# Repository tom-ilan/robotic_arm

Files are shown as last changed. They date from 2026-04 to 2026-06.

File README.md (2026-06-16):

# 🦾 3-Axis Robotic Arm Controller & Simulator

A high-performance, precision-controlled 3-axis robotic arm project featuring a mathematical Inverse Kinematics (IK) engine, a robust Arduino-based servo controller with EEPROM state persistence, and interactive command-line and graphical dashboards.

> 🎬 **Demo** — Watch smooth_glider.py in action

---

## 🌟 Key Features

* **Precision Inverse Kinematics**: Custom analytical geometric IK engine solving joint coordinates in real time for precise target tracking.
* **Sub-Degree Resolution Serial Protocol**: A binary serial packet protocol scaling float angles to centidegrees (1/100th of a degree) and packing them into compact 16-bit big-endian structures for optimal transmission speed and high accuracy.
* **Non-Volatile Memory (EEPROM)**: The Arduino firmware caches successful servo coordinates to the EEPROM on every valid command, preventing joint snapping/jerking when powered off and rebooted.
* **Startup Position Handshake**: On boot, the Arduino reads its last-known position from EEPROM (clamping uninitialized states to a safe $90^\circ$), moves there, and outputs an `INIT:base,bottom,top,gripper` handshake signal to coordinate seamless starting glides.
* **Multi-Mode Trajectory Planners**: Supports both immediate step-coordinate jumps (`rigid_glider.py`) and joint-space linear angle interpolation (`smooth_glider.py`) for smooth path planning.
* **3D Printable Mechanical Assets**: CAD models (STL/3MF/F3Z formats) located in the workspace under `version_1/` for physical arm manufacturing and prototyping.

---

# Assembly

## 🛠️ Hardware Requirements

1. **Microcontroller**: Arduino Uno, Nano, or similar AVR/ARM board.
2. **Servos**: 4x standard micro-servos (e.g., SG90 or MG90S).
   - **Servo 1**: Turntable Base (Pin 3)
   - **Servo 2**: Shoulder / Lower Arm (Pin 5)
   - **Servo 3**: Elbow / Upper Arm (Pin 6)
   - **Servo 4**: Gripper Claw (Pin 9)
3. **Power**: 5V external power supply (recommended for servos to prevent USB current limit trip).
4. **Screws**: 
    - 8x **M2 x 10mm**
    - 4x **M2.5 x 5mm**

## 🖨️ 3D Printing the parts

Located under **version_1** in the **final_print_parts** folder is the full final .stl files for printing, the settings used for a Bambu Labs P2S were the generic print settings with supports on. 

## 🪛 Assembly

1. After 3D printing the parts place the first servo into the base

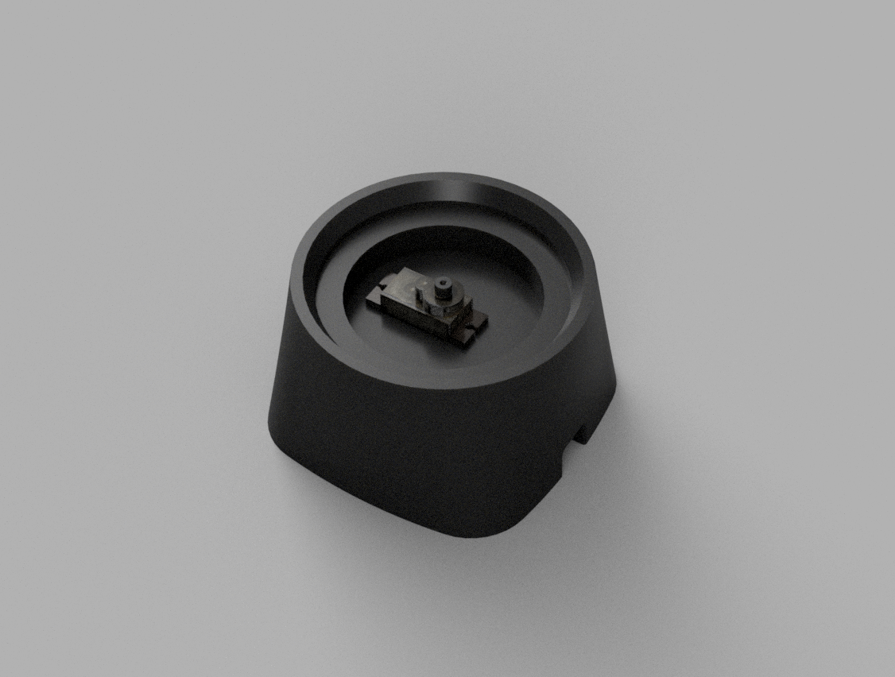
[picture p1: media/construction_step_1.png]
Step 1 - Servo seated in base housing


2. Then screw the top of the base onto the the servo

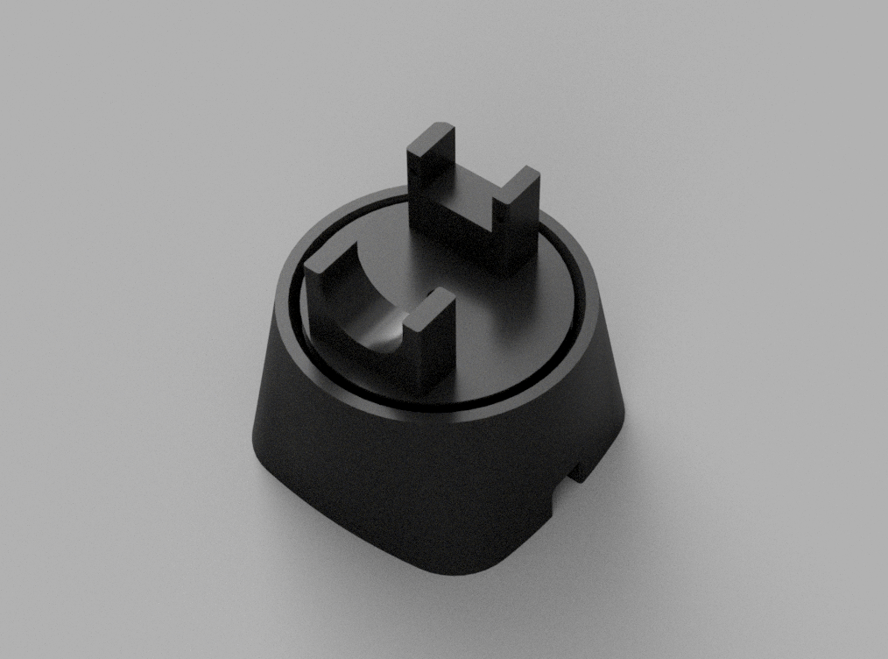
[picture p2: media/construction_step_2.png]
Step 2 - Base top placed onto servo


3. Now screw the lower arm and servo together

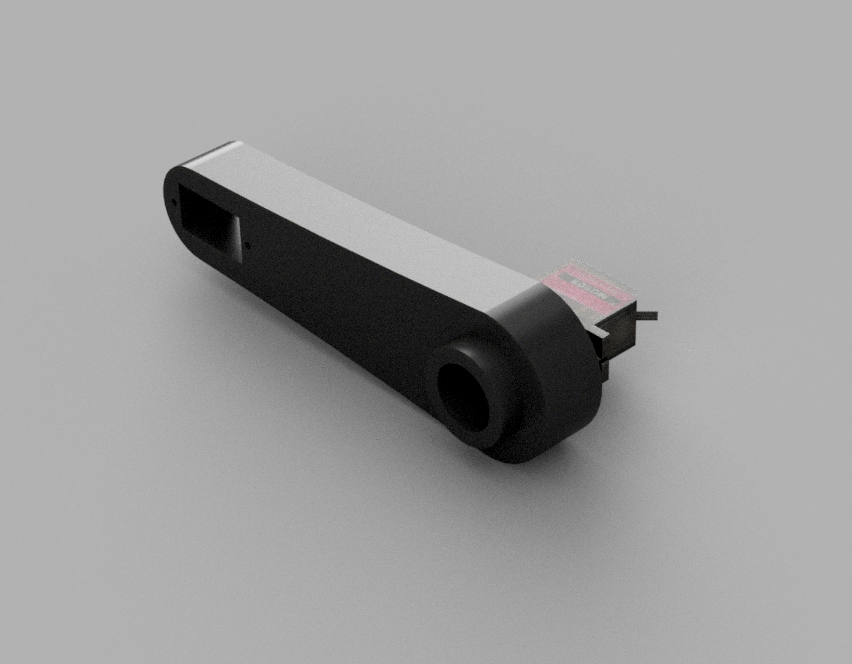
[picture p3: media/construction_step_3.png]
Step 3 - Lower arm assembled with servo


4. Slot the lower arm into the base 

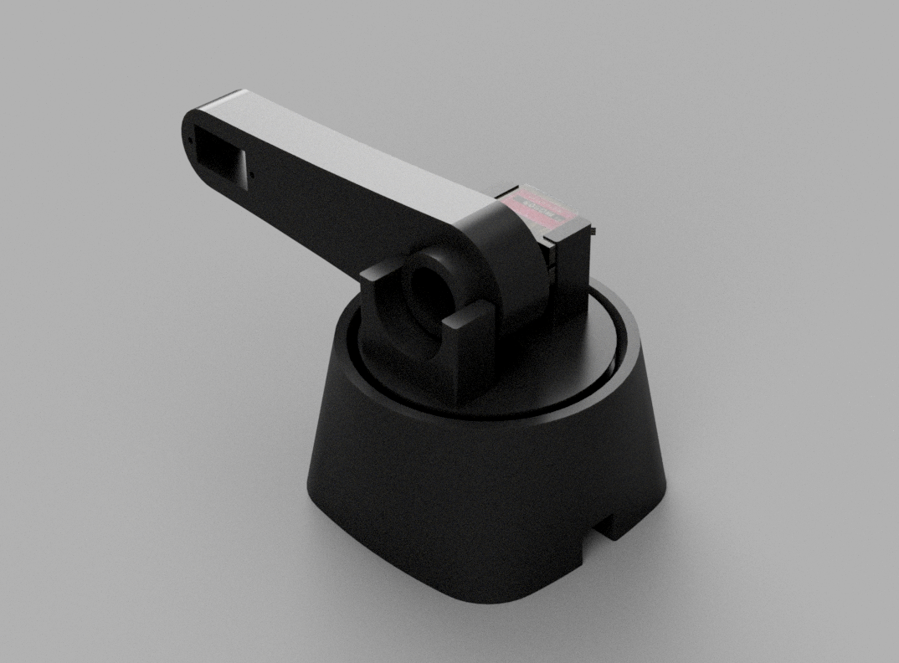
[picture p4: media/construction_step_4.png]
Step 4 - Lower arm slotted into base


5. Insert the servo to the end of the lower arm and upper arm and screw the upper arm to the lower arm 

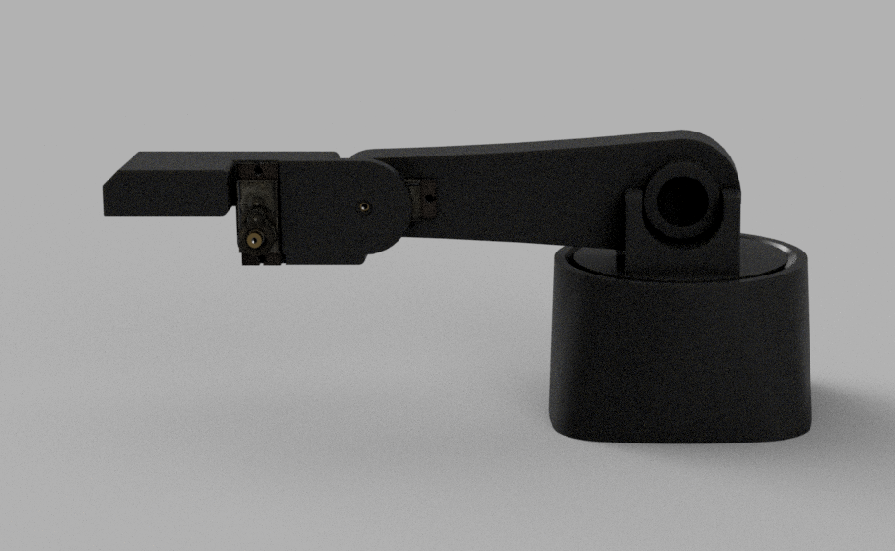
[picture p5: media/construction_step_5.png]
Step 5 - Upper arm connected at elbow joint


6. Screw the gripper onto the end of the upper arm

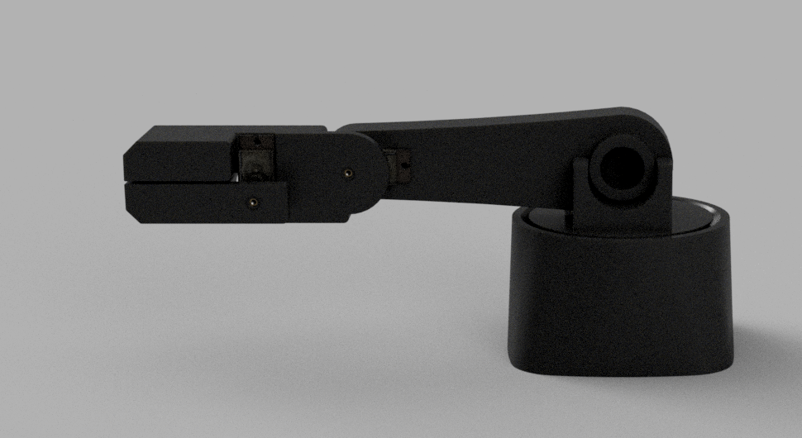
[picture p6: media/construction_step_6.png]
Step 6 - Gripper attached, full assembly complete

---

## 🚀 Getting The Arm Moving

### 1. Arduino Setup
1. Open [robot_arm_controller.ino](robot_arm_controller/robot_arm_firmware/robot_arm_controller.ino) in the **Arduino IDE**.
2. Connect your Arduino board via USB.
3. Select your Board and Port from the Tools menu.
4. Click **Upload** to flash the firmware.

### 2. Python Environment Setup
Install the necessary Python dependencies for the UI and serial driver:
```bash
pip install pygame pyserial pandas
```

### 3. Running the Controllers

#### 🎮 Interactive CLI (TUI) Modes:
* **Cartesian Control (X, Y, Z, Gripper)**:
  Allows typing target millimeter coordinates directly into the console.
  ```bash
  python robot_arm_controller/point_tui.py
  ```
* **Raw Angle Control (Base, Bottom, Top, Gripper)**:
  Allows writing raw joint-space angles.
  ```bash
  python robot_arm_controller/angle_tui.py
  ```

#### 📈 Waypoint Macro Executions:

* **Smooth Glider (Interpolated)**:
  Prompts for your waypoint CSV path, handshakes startup coordinates from the Arduino, glides smoothly to the starting point, and interpolates through each subsequent waypoint segment.
  ```bash
  python robot_arm_controller/smooth_glider.py
  ```
* **Rigid Glider (Immediate Steps)**:
  Prompts for a CSV path and executes sequential coordinates by sleeping for the designated duration between movements.
  ```bash
  python robot_arm_controller/rigid_glider.py
  ```

* **CSV formating**:

  **x cordinate** (mm), **y cordinate** (mm), **z cordinate** (mm), **gripper angle** (degree), **time** (seconds)
---

## 📐 Serial Communication Protocol

To ensure sub-degree accuracy without transmission overhead, the system uses a custom binary protocol using big-endian. Angles are scaled to **centidegrees** (multiplied by 100), converted to signed 16-bit integers, and sent as an 8-byte packet:

| Byte Index | Data Packed | Description |
|---|---|---|
| **0** | `Base High Byte` | Most Significant Byte of Base Angle |
| **1** | `Base Low Byte` | Least Significant Byte of Base Angle |
| **2** | `Shoulder High Byte` | Most Significant Byte of Shoulder/Bottom Angle |
| **3** | `Shoulder Low Byte` | Least Significant Byte of Shoulder/Bottom Angle |
| **4** | `Elbow High Byte` | Most Significant Byte of Elbow/Top Angle |
| **5** | `Elbow Low Byte` | Least Significant Byte of Elbow/Top Angle |
| **6** | `Gripper High Byte` | Most Significant Byte of Gripper Angle |
| **7** | `Gripper Low Byte` | Least Significant Byte of Gripper Angle |

---

## ⚙️ Mathematical Specification

The inverse kinematics algorithm maps $3\text{D}$ space $(X, Y, Z)$ into cylindrical coordinates, using `atan2` for robust base rotation, and solves planar arm equations via the Law of Cosines:

$$d = \sqrt{x_{inline}^2 + z_{inline}^2}$$

$$\theta_2 = \arccos\left(\frac{L_1^2 + L_2^2 - d^2}{2 L_1 L_2}\right)$$

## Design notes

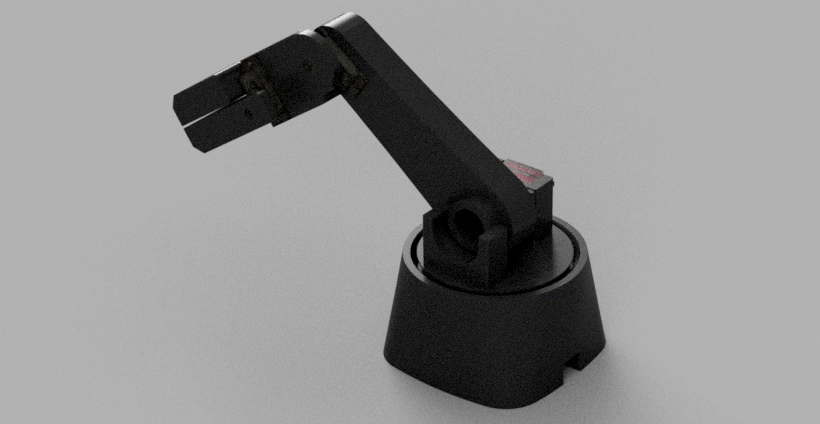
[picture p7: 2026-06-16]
media/social_image.png

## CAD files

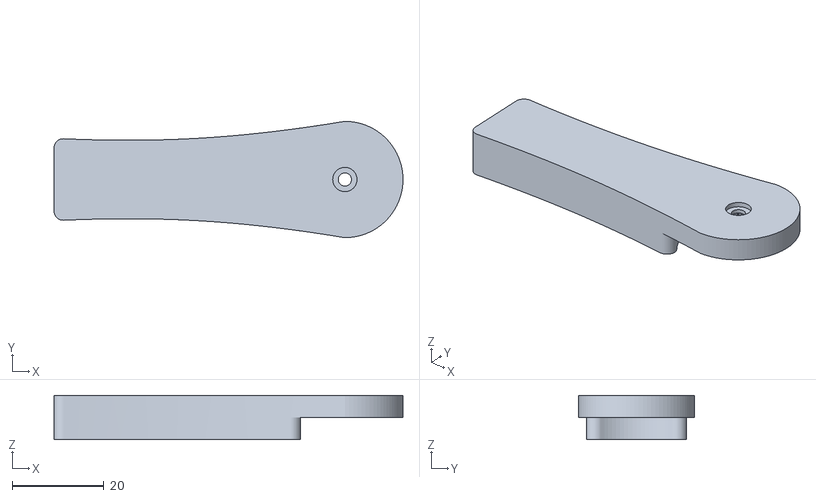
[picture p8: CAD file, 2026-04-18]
version_1/1.1/Upper_arm_2.stl
76.2 x 25.4 x 9.70

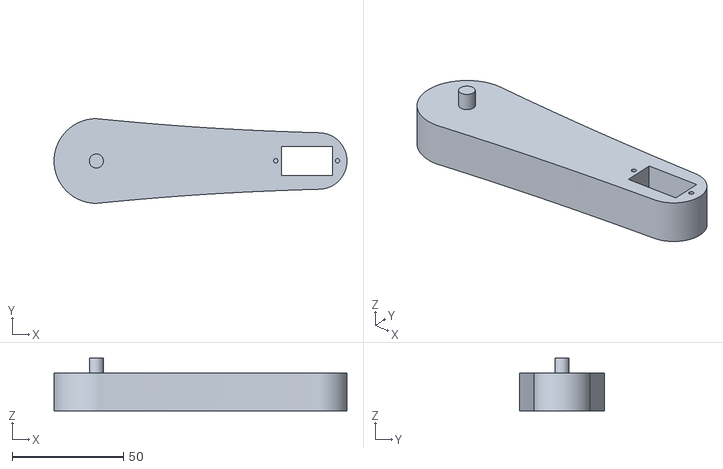
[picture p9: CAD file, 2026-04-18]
version_1/1.2/Lower_arm_2.stl
131.7 x 38.1 x 23.7

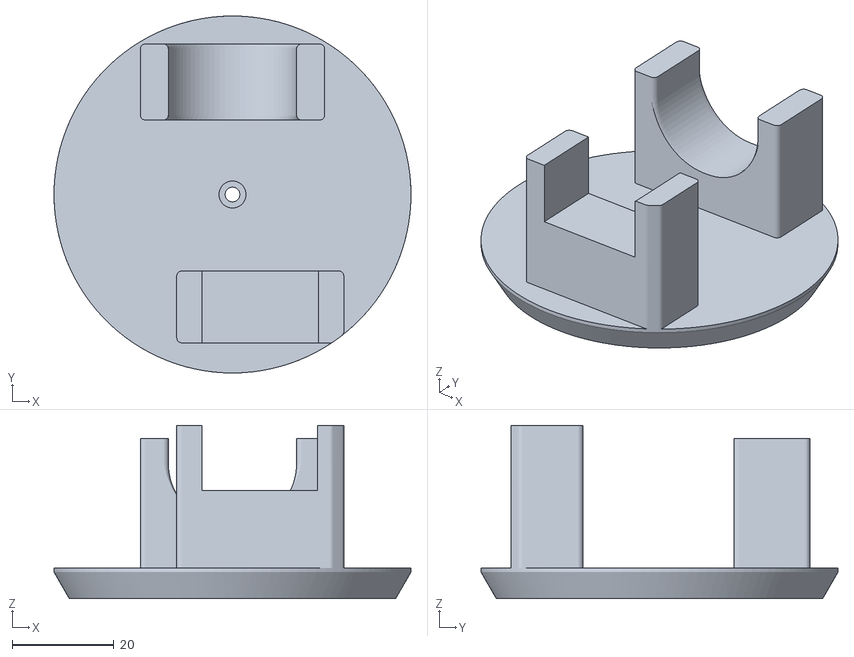
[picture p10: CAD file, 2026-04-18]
version_1/1.3/top_base_3.stl
70.0 x 70.0 x 34.0

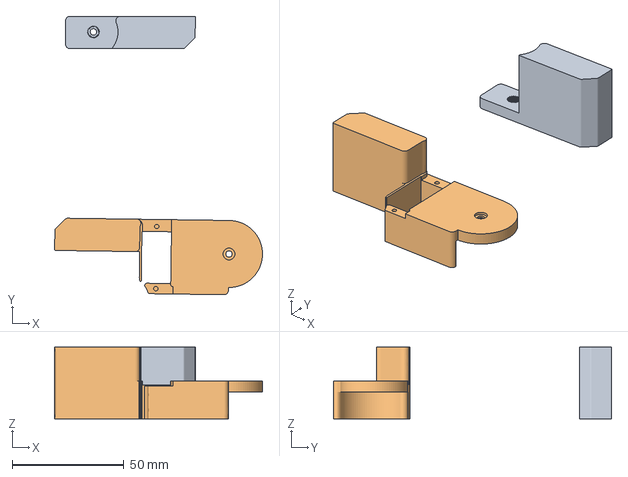
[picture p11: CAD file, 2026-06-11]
version_1/1.4/girpper.3mf
93.1 x 124.6 x 32.0 mm
girpper.stl
Top_arm_gripper_1.stl

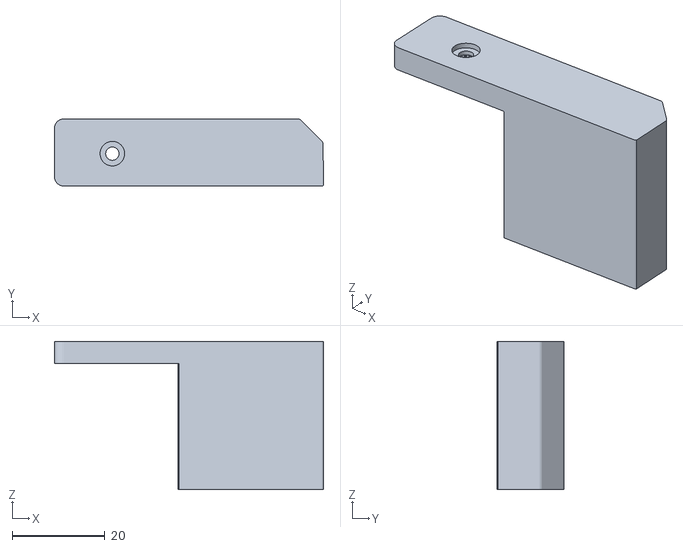
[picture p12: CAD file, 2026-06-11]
version_1/1.5/gripper_arm_2.stl
58.1 x 14.5 x 32.0

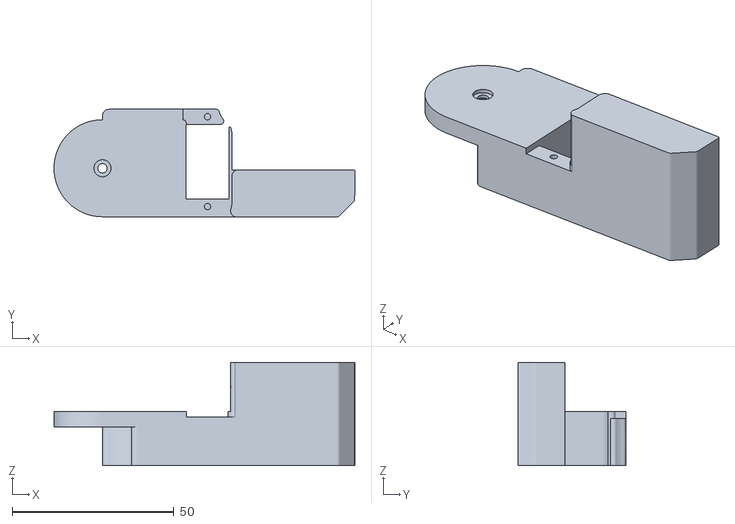
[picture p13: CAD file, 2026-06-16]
version_1/final_print_parts/uppper_arm_body_final_1.stl
93.1 x 33.2 x 32.0

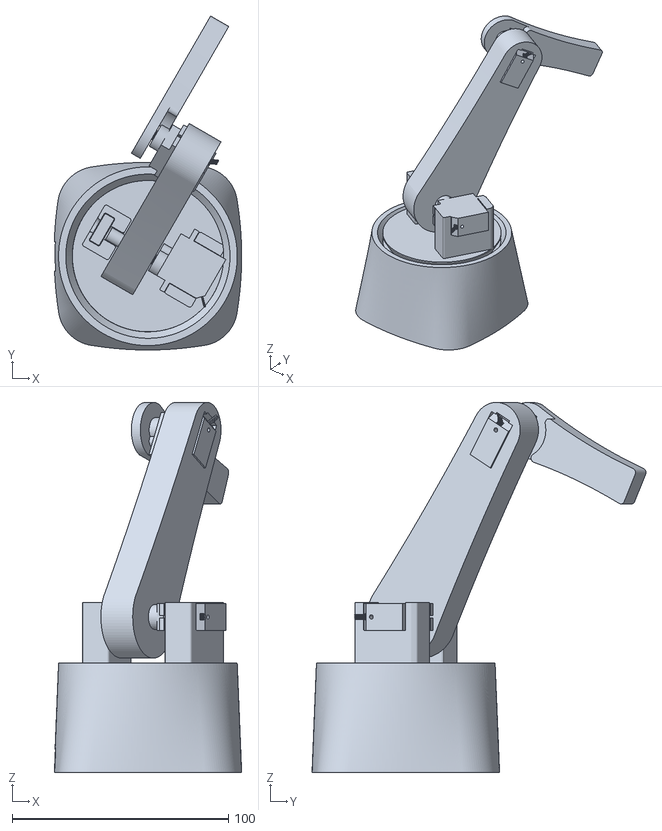
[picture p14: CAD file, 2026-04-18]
version_1/Robotic_arm_final_1.stl
86.7 x 154.6 x 171.3

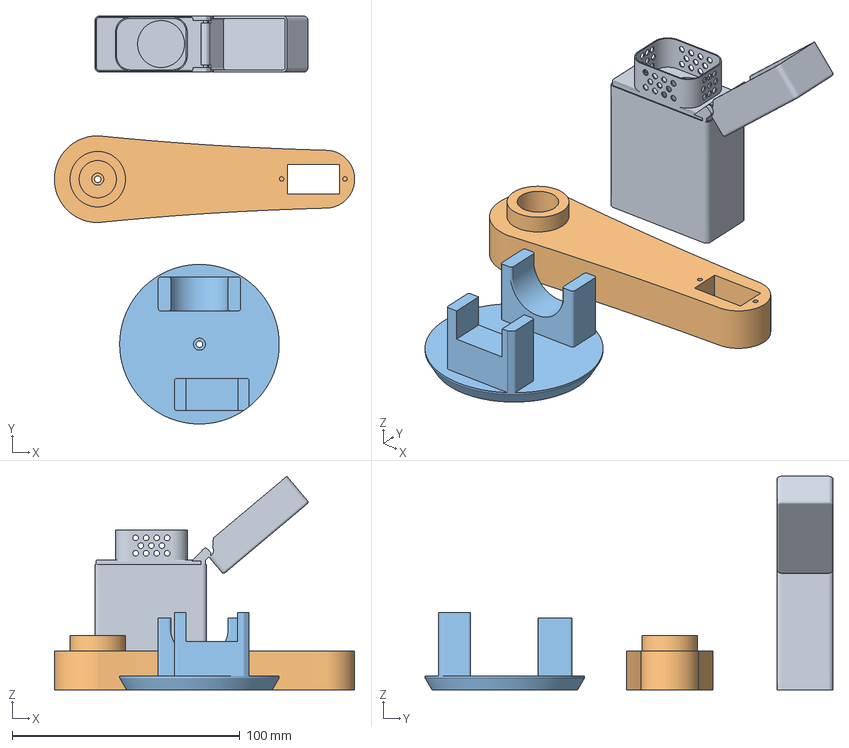
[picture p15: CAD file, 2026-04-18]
version_1/1.3/robotic_arm_print_2.3mf
131.7 x 179.0 x 93.7 mm
Lighter_Brayden.stl
Lower_arm_3.stl
top_base_3.stl

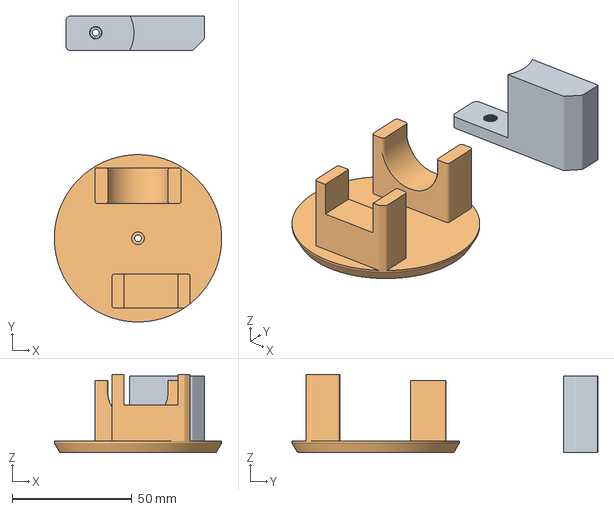
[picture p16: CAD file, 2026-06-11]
version_1/1.4/gripper_arm_2.3mf
70.0 x 128.0 x 32.8 mm
gripper_arm_2.stl
Base_top_4.stl

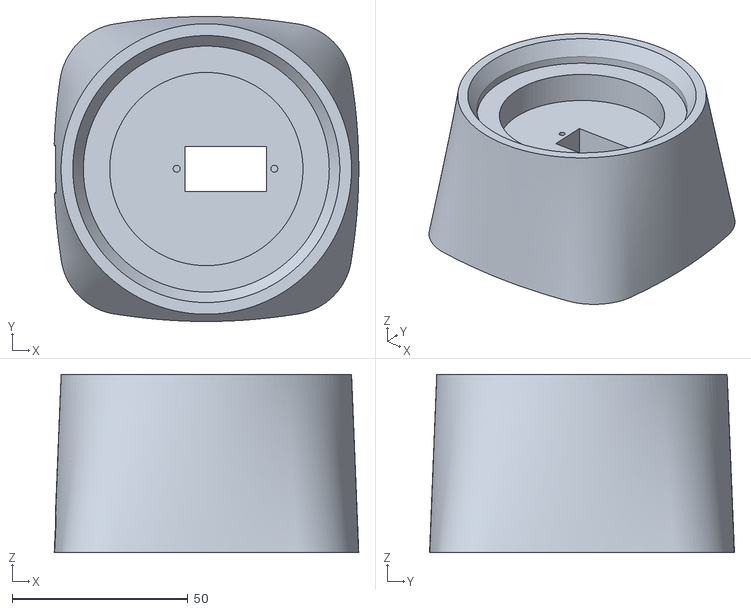
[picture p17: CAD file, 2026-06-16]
version_1/final_print_parts/base_bottom_final_1.stl
86.7 x 86.8 x 50.8

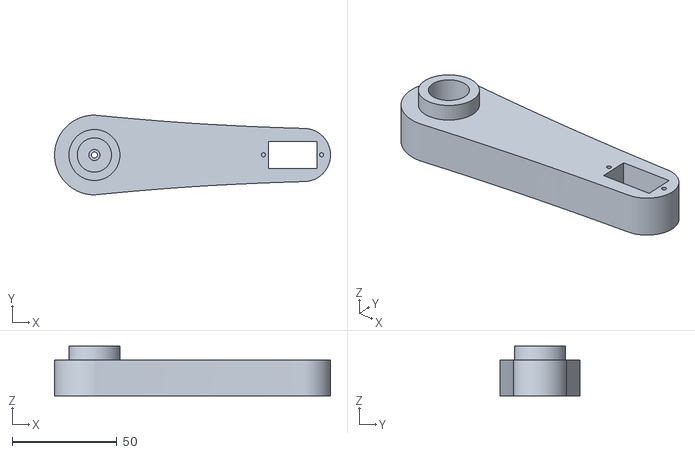
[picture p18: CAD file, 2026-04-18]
version_1/1.3/Lower_arm_3.stl
131.7 x 38.1 x 23.7

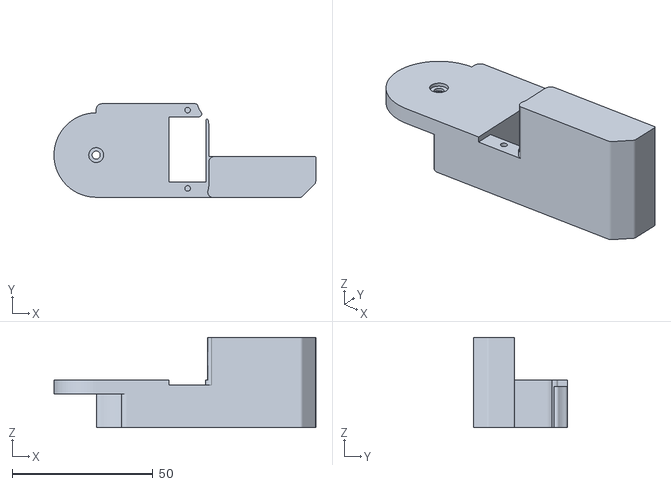
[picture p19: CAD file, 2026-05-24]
version_1/1.4/Top_arm_gripper_1.stl
93.1 x 33.2 x 32.0

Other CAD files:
version_1/1.1/Top_Base.stl
version_1/1.2/Base_top_2.stl
version_1/Top_Base.stl
version_1/1.1/Lower_arm.stl
version_1/Base_top_2.stl
version_1/final_print_parts/lower_arm_final_1.stl
version_1/1.1/Base.stl
version_1/1.1/Base_2.stl
version_1/1.1/Joint_Stopper_2.stl
version_1/1.1/Robotic_Arm_Print_1.3mf
version_1/1.4/girpper.stl
version_1/Lower_arm.stl
version_1/final_print_parts/base_final_top_1.stl

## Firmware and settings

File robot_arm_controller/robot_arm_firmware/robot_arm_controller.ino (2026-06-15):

#include <Servo.h>
#include <EEPROM.h>

// Servo set up
Servo servoOne;
Servo servoTwo;
Servo servoThree;
Servo servoFour;

void setup() {
  Serial.begin(9600);

  // Read positions from EEPROM
  int s1 = EEPROM.read(0);
  int s2 = EEPROM.read(1);
  int s3 = EEPROM.read(2);
  int s4 = EEPROM.read(3);

  // If EEPROM is uninitialized (255) or out of servo range, default to 90 degrees
  if (s1 < 0 || s1 > 180) s1 = 90;
  if (s2 < 0 || s2 > 180) s2 = 90;
  if (s3 < 0 || s3 > 180) s3 = 90;
  if (s4 < 0 || s4 > 180) s4 = 90;

  // Write initial positions to prevent the default 90-degree attach snap
  servoOne.write(s1);
  servoTwo.write(s2);
  servoThree.write(s3);
  servoFour.write(s4);

  // Print startup angles in a recognizable single-line format
  Serial.print("INIT:");
  Serial.print(s1);
  Serial.print(",");
  Serial.print(s2);
  Serial.print(",");
  Serial.print(s3);
  Serial.print(",");
  Serial.println(s4);

  // Servo attaching to pins with explicit pulse range
  servoOne.attach(3, 500, 2500); // base
  servoTwo.attach(5, 500, 2500); //bottom
  servoThree.attach(6, 500, 2500); //top
  servoFour.attach(9, 500, 2500); //gripper
}

void loop() {

  /* 
  1) Checks if there is incoming data in serial from python servo controller
  2) If there is assign each number (0-180) received to which servo it will control
  */

  if (Serial.available() >= 8) {

    byte servoOneBig = Serial.read();
    byte servoOneLittle = Serial.read();

    byte servoTwoBig = Serial.read();
    byte servoTwoLittle = Serial.read();

    byte servoThreeBig = Serial.read();
    byte servoThreeLittle = Serial.read();

    byte servoFourBig = Serial.read();
    byte servoFourLittle = Serial.read();

    // Print raw bytes separately (avoid second-argument overload)
    Serial.print("Raw bytes -> S1: ");
    Serial.print((int)servoOneBig);
    Serial.print(" ");
    Serial.print((int)servoOneLittle);
    Serial.print("  S2: ");
    Serial.print((int)servoTwoBig);
    Serial.print(" ");
    Serial.print((int)servoTwoLittle);
    Serial.print("  S3: ");
    Serial.println((int)servoThreeBig);
    Serial.print(" ");
    Serial.println((int)servoThreeLittle);
    Serial.print("  S4: ");
    Serial.println((int)servoFourBig);
    Serial.print(" ");
    Serial.println((int)servoFourLittle);

    int servoOneInput = twoByteCentiDegreeTooFloat(servoOneBig, servoOneLittle);
    int servoTwoInput = twoByteCentiDegreeTooFloat(servoTwoBig, servoTwoLittle);
    int servoThreeInput = twoByteCentiDegreeTooFloat(servoThreeBig, servoThreeLittle);
    int servoFourInput = twoByteCentiDegreeTooFloat(servoFourBig, servoFourLittle);

    // Prints what each servo got as input
    Serial.print("Decoded deg -> S1: ");
    Serial.print(servoOneInput);
    Serial.print("  S2: ");
    Serial.print(servoTwoInput);
    Serial.print("  S3: ");
    Serial.println(servoThreeInput);
    Serial.print("  S4: ");
    Serial.println(servoFourInput);

    //Writes the angles inputed to each servo
    floatServoDriver(servoOne, servoOneInput);
    floatServoDriver(servoTwo, servoTwoInput);
    floatServoDriver(servoThree, servoThreeInput);
    floatServoDriver(servoFour, servoFourInput);

    EEPROM.write(0, servoOneInput);
    EEPROM.write(1, servoTwoInput);
    EEPROM.write(2, servoThreeInput);
    EEPROM.write(3, servoFourInput);
  }
}

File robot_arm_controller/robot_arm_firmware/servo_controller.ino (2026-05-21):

#include <Servo.h>

// This function recives two bytes which make up one angle in centidegrees (byte1 and byte2) and returns the combined float
float twoByteCentiDegreeTooFloat(byte byte1, byte byte2){
  // promote to int before shifting so the high byte isn't lost
  int high = ((int)byte1) << 8;
  int centiDegreeByte = high | (int)byte2;
  float centiDegreeFloat = (float)centiDegreeByte;

  // Converts centidegrees to degrees
  float degreeFloat = centiDegreeFloat / 100.0;

  return degreeFloat;
}


void floatServoDriver(Servo &servo, float degree){
   // Map degrees (0-180) to microseconds (500-2500µs)
   int microseconds = map(degree, 0, 180, 500, 2500);
  
   servo.writeMicroseconds(microseconds);
   Serial.println(microseconds);
   delay(100);
}

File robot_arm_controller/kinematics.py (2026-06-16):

import math

# PHYSICAL CONFIGURATION
# Easily adjust the mechanical arm segment lengths here:
BOTTOM_ARM_LENGTH_MM = 100.0   # Shoulder-to-Elbow length (Shoulder)
TOP_ARM_LENGTH_MM    = 64.0    # Elbow-to-End-Effector length (Elbow)

TOP_MOUNTING_OFFSET_ANGLE_RADIANS = -math.pi / 2

# Compute the robot arm angles,
# given a target x, y and z.
def get_robot_angles_radians(x_mm: float, y_mm: float, z_mm: float) -> tuple[float, float, float]:
   
   # Compute base angle.
   base_angle_radians = math.atan2(y_mm, x_mm)

   # If the base angle is less than 0,
   # we cannot move the servo to that position.
   # Instead, we move the arm to the opposite position,
   # And invert the target later.
   inverted_x = base_angle_radians < 0
   if inverted_x: 
      base_angle_radians += math.pi

   # Transform x, y, and z coordinates to post-base angle positioning,
   # where the arm is in line with the target.
   in_line_x_mm = math.sqrt(x_mm ** 2 + y_mm ** 2) * (-1 if inverted_x else 1)
   in_line_z_mm = z_mm

   # Get distance and angle to target.
   # Angle relative to x axis.
   target_distance_mm = math.sqrt(in_line_z_mm ** 2 + in_line_x_mm ** 2)
   target_angle_radians = math.atan2(in_line_z_mm, in_line_x_mm)

   # Apply cosine law to find top angle.
   top_angle_radians = math.acos(
      (TOP_ARM_LENGTH_MM ** 2 + BOTTOM_ARM_LENGTH_MM ** 2 - target_distance_mm ** 2) / 
      (2 * TOP_ARM_LENGTH_MM * BOTTOM_ARM_LENGTH_MM)
   )
   
   # Apply sine law to find bottom angle.
   target_to_bottom_angle_radians = math.asin(
      (TOP_ARM_LENGTH_MM * math.sin(top_angle_radians)) /
      target_distance_mm
   )
   
   # Apply offset from target.
   bottom_angle_radians = target_angle_radians + target_to_bottom_angle_radians

   # Apply offset to top angle.
   top_angle_radians += TOP_MOUNTING_OFFSET_ANGLE_RADIANS

   # Make sure all angles are positive.
   assert math.pi >= base_angle_radians >= 0
   assert math.pi >= bottom_angle_radians >= 0
   assert math.pi >= top_angle_radians >= 0

   return base_angle_radians, bottom_angle_radians, top_angle_radians

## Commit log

2026-04-18 First commit for the robotic arm
    [Base.stl, Base_2.stl, Base_top_2.stl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]
2026-04-20 Got kinematics working
    [Base_2.stl, Base_top_2.stl, Joint_Stopper_2.stl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]
2026-04-21 Fixed bugs and cleaned code
    [kinematics.py]
2026-05-18 Float servo movemnt, can only move between 45 and 135 degrees...
2026-05-20 fixed position limit bug
    [go_to.py, robot_arm_controller.ino]
2026-05-23 fixed file locations
    [Base_2.stl, Base_top_2.stl, Joint_Stopper_2.stl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]
2026-05-24 started work on GUI and created gripper for the top part of arm
    [Top_arm_gripper_1.stl, girpper.stl]
2026-06-11 added a working gripper
    [Base_top_4.stl, girpper.3mf, gripper_arm_2.3mf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]
2026-06-15 renamed files and organized versions
    [Base_top_4.stl, gripper_arm_2.stl]
2026-06-16 name fix i hope
    [glide_to.py, go_to.py, kinematics.py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]
2026-06-16 added final_print_parts
    [base_bottom_final_1.stl, base_final_top_1.stl, lower_arm_final_1.stl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]
